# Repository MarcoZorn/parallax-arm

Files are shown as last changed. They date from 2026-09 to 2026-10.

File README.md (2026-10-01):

# Parallax Arm

Braccio robotico da scrivania a 4 assi, **solo servo SG90**, interamente stampabile in PLA, **zero saldature**.
Lo pilota un ESP32 e si controlla da una web app locale con digital twin 3D.

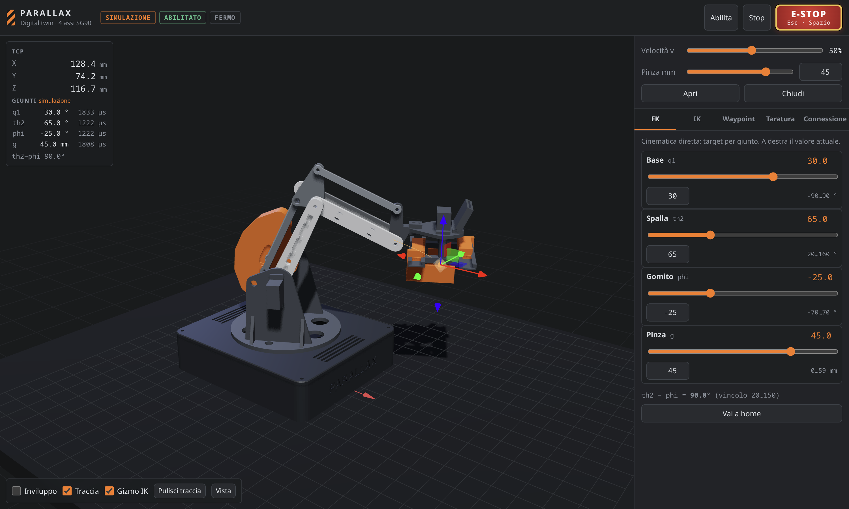
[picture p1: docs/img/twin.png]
Digital twin


| | |
|---|---|
| Assi | base, spalla, gomito + pinza parallela; pinza **sempre orizzontale** (doppio parallelogramma) |
| Sbraccio | 188 mm dall'asse spalla (th2 − phi ≥ 35°) |
| Payload | 50 g anche con la ESP32-CAM montata (SF ≥ 2 sulla coppia di stallo: `calc/` + simulazione MuJoCo in `sim/`) |
| Pinza | cremagliera simmetrica, corsa 0–59 mm |
| Motori | 4 × SG90 180°: spalla e gomito sulla torretta, contrappesi con piombi da pesca |
| Elettronica | ESP32 DevKit V1, PWM diretto dai GPIO, caricatore USB 5V 3A, morsetti WAGO |
| Software | firmware PlatformIO (WebSocket, planner sincronizzato), web app Vite + Three.js (FK, IK, waypoint, taratura, simulazione) |

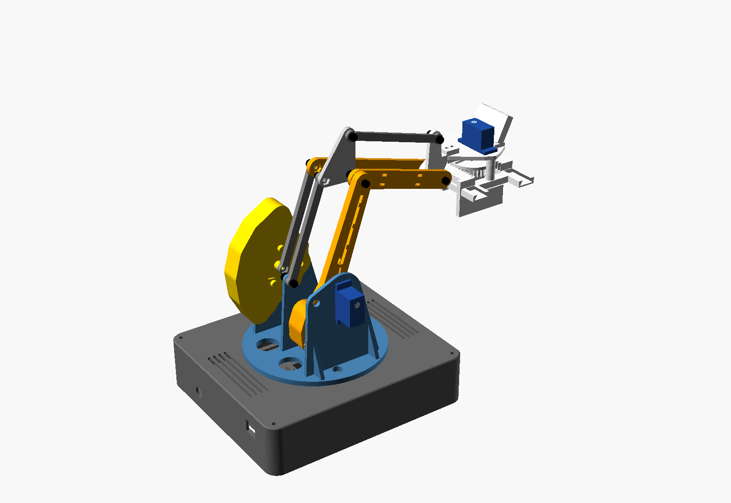
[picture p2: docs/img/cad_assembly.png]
Assieme CAD


## Come è fatto

Un SG90 da 1.6 kg·cm non regge un braccio seriale.

**Il servo del gomito è sulla torretta**, accanto a quello della spalla, e muove l'avambraccio con una manovella e una biella. Così nessun motore viaggia sul braccio.

Due parallelogrammi passivi tengono la pinza orizzontale, e i piombi da pesca sulle code di manovella e braccio compensano la gravità a qualsiasi angolo.

Ogni numero si può rilanciare:
- `python3 calc/torque.py` per le coppie, con le masse ricavate dagli STL;
- `cad/assembly.scad` per le collisioni tra tutte le parti, viti e dadi compresi, su una griglia di pose.

## Struttura

```
calc/torque.py        coppie statiche, contrappesi, pinza, corrente (con assert)
cad/params.scad       unica fonte delle quote e delle tolleranze
cad/*.scad            base, torretta, braccio, manovella, catena gomito, polso+pinza, provino tolleranze
cad/assembly.scad     assieme + verifica collisioni
cad/export.sh         rigenera STL di stampa, modelli del twin e rig.json
cad/stl/              STL pronti, già orientati sul piatto
firmware/             ESP32 (PlatformIO): LEDC, WiFi STA/AP, WebSocket, NVS, test nativi
web/                  digital twin e controllo (Vite + Three.js), build -> firmware/data
docs/                 analisi, cablaggio, protocollo, stampa e montaggio
```

## Avvio rapido

1. Stampa gli STL di `cad/stl/` (circa 230 g di PLA, niente supporti) e monta: [docs/04-stampa-e-montaggio.md](docs/04-stampa-e-montaggio.md).
2. Il provino di tolleranze è facoltativo: serve solo se qualcosa non calza.
3. Cablaggio: [docs/02-cablaggio.md](docs/02-cablaggio.md).
4. Carica firmware e web app:
   ```bash
   cd web && npm install && npm run build
   cd ../firmware && pio run -e esp32dev -t upload && pio run -e esp32dev -t uploadfs
   ```
   Poi apri `http://braccio.local`, oppure l'AP `BRACCIO` su `http://192.168.4.1`.

Senza hardware: `cd web && npm install && npm run dev`. La web app gira in simulazione con lo stesso profilo di moto del firmware.

## Test

```bash
python3 calc/torque.py                    # punti di progetto delle coppie
cd firmware && pio test -e native         # planner, limiti, mappatura µs
cd web && npm test                        # FK/IK andata e ritorno, profilo di moto
cad/check_grid.sh                         # collisioni su tutta la griglia di pose (lento)
sim/software/run_all.sh                   # firmware = twin, fuzz, protocollo end-to-end, UI
python3 sim/structural/run_all.py         # strutture, perni, ingranaggi, tolleranze (Monte Carlo)
python3 sim/electrical/run_all.py         # alimentazione nel tempo
sim/.venv/bin/python sim/dynamics/run_all.py   # dinamica MuJoCo (python3 -m venv sim/.venv && sim/.venv/bin/pip install mujoco numpy scipy matplotlib)
```

Esiti e limiti: [docs/05-verifiche.md](docs/05-verifiche.md).

## Documenti

- [01 — Analisi carichi e scelte di progetto](docs/01-analisi-e-piano.md)
- [02 — Cablaggio senza saldature](docs/02-cablaggio.md)
- [03 — Cinematica, taratura e protocollo](docs/03-protocollo.md)
- [04 — Stampa, ferramenta e montaggio](docs/04-stampa-e-montaggio.md)
- [05 — Verifiche e simulazioni](docs/05-verifiche.md): dinamica MuJoCo, strutture e tolleranze, alimentazione, software

## Licenza

MIT, vedi [LICENSE](LICENSE).

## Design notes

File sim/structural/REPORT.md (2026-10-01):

# BRACCIO — analisi strutturale e di tolleranze

Generato da `sim/structural/run_all.py` il 2026-10-01 sulle quote correnti di `cad/*.scad`
e sulle masse di `calc/torque.py`. PLA su Kobra S1: ugello 0.4, layer 0.2, 3 perimetri, gyroid 20%.
Materiale: E 3200 MPa nel piano / 2600 tra layer, rottura 50 / 27 MPa,
taglio interlaminare 15 MPa; sezioni con guscio pieno (perimetri 1.2, top/bottom 0.8) e nucleo gyroid al 12% di
rigidezza. Orientamenti di stampa: quelli di `cad/export.sh`. Carico di verifica: 50 g + ESP32-CAM, 2 piombi sulla manovella
e 4 sulla coda del braccio (punto di progetto di docs/01).

## Esiti

| verifica | ESITO | in breve |
|---|---|---|
| 1. Link e bielle: tensioni e freccia al TCP | **KO** | tensioni OK nei link (SF din min 1.9), dito ganascia SF 2.7 allo stallo; freccia TCP statica 5.5 mm in home, 26 mm a sbraccio |
| 2. Perni M3, fori e alberi dei servo | **KO** | perno E: p bordo din 47.9 MPa, vite 724 MPa; momento albero spalla 708 N·mm statico |
| 3. Pignone e cremagliere m1 + controlli STL | **OK** | denti OK (σ pignone 2.4 MPa allo stallo); ricoprimento 1.53 col gioco; ganasce: ok |
| 4. Code di rondine: attrito e impuntamento | **riserva** | presa 1.9 N/dito con μ 0.35 (rendimento 0.40), richiesti 1.6 N; impuntamento solo con μ > 1.08 |
| 5. Incastri a scatto (culla ESP32) | **OK** | ε 0.20% (ok), P(scheda non trattenuta) 0% |
| 6. Autofilettanti e dadi incassati | **riserva** | estrazione OK; sedi dadi: ok, parete minima 0.55 mm |
| 7. Scorrimento viscoso e temperatura | **KO** | servo gomito in home 50 g: +59 K; freccia TCP x1.4 dopo 100 h a 23 °C |
| 8. Monte Carlo delle tolleranze | **KO** | home: accuratezza p95 16.2 mm, RP p95 14.9 mm (scenario B); squadretta non entra 0%, SG90 nelle guance 10% |

Il quadro in una riga: **i pezzi non si rompono, il braccio è cedevole**. Le tensioni sono basse quasi ovunque (eccezioni: il
dito della ganascia, il perno E e gli alberi dei servo). La rigidezza invece è dominata dall'eccentricità di ~33 mm tra il piano
del braccio e quello della biella motrice: la forza della biella flette fuori piano braccio, guancia e albero del servo spalla, e il
parallelogramma trasforma quelle piccole rotazioni in rotazioni dell'avambraccio, amplificate da 1/sin(e) vicino a e = 20°.
Ci sono poi tre difetti CAD che vanno corretti comunque (ganasce, dadi della staffa, dado di U corto).

## 1. Link e bielle: tensioni e freccia al TCP — KO

Carichi: 50 g + ESP32-CAM, 2 piombi manovella + 4 braccio. Statico = posa peggiore sulla griglia
(th2 20…160, phi −70…70, vincolo e = th2 − phi in 20…150, passo 5°). Dinamico = statico x 2.
Stallo = servo gomito a 2 kg·cm contro un ostacolo con e = 20° (biella 28.7 N).
Ammissibili: 50 MPa nel piano dei layer, 27 MPa tra layer, 15 MPa taglio interlaminare.
ESITO sul dinamico: OK se SF ≥ 2, riserva se 1.2–2, KO sotto.

| membro | posa peggiore th2/phi | σ stat MPa | σ din MPa | σ stallo MPa | amm. MPa | SF din | ESITO | nota |
|---|---|---|---|---|---|---|---|---|
| braccio (in piano) | 20/0 | 2.97 | 5.95 | 6.69 | 50 | 8.4 | OK | flessione nel piano + fuori piano + torsione, sezione al foro cavo x=20 |
| avambraccio piastra R (di fianco) | 60/0 | 0.90 | 1.80 | 2.02 | 50 | 27.8 | OK | momento della leva B al perno E |
| avambraccio taglio tra layer | 20/0 | 0.34 | 0.68 | 0.77 | 15 | 22.0 | OK | taglio all'asse neutro = piano dei layer |
| biella motrice (assiale) | 20/0 | 1.18 | 2.36 | 2.65 | 50 | 21.2 | OK | sezione netta all'occhio |
| biella livell. 1 (assiale) | 20/-20 | 0.56 | 1.13 | 1.27 | 50 | 44.4 | OK | sezione netta all'occhio |
| biella livell. 2 (assiale) | 20/-70 | 0.50 | 1.00 | 0.39 | 50 | 50.0 | OK | sezione netta all'occhio |
| triangolo (leve P1/U) | 20/-20 | 1.89 | 3.78 | 4.26 | 50 | 13.2 | OK |  |
| manovella | 20/0 | 4.53 | 9.06 | 10.20 | 50 | 5.5 | OK | piastra 4 mm, sezione 12 x 4 al mozzo |
| montante G (in piedi) | 20/-20 | 3.60 | 7.20 | 8.11 | 27 | 3.7 | OK | lastra 16 x 3 alla base, tensione verticale tra layer |
| guancia spalla (in piedi) | 55/35 | 5.33 | 10.65 | 7.20 | 27 | 2.5 | OK | flessione fuori piano sopra i fazzoletti |
| guancia spalla torsione | 20/0 | 3.88 | 7.76 | 8.74 | 15 | 1.9 | riserva | torsione attorno a Z |
| staffa polso (leva V) | 20/-70 | 0.49 | 0.99 | 1.11 | 50 | 50.5 | OK |  |
| dito ganascia: torsione gambo | presa | 4.45 | - | 5.56 | 15 | 2.7 (stallo) | OK | gambo 6 x 5, leva 30 mm, taglio sui piani dei layer |

Dito ganascia: freccia sotto la presa di stallo 0.82 mm. Con gambo 6 mm e dito spesso 5 mm il taglio
scende da 5.6 a 5.6 MPa (SF 2.7).

**Tensioni basse ovunque, tranne il dito.** I link reggono con margini ampi: il problema è la **rigidezza**.

#### Freccia elastica al TCP (statica, mm; colonne x,z nel piano, y laterale)

La catena è sommata risolvendo i due parallelogrammi con le cedevolezze di ogni elemento (`chain.py`).
Il meccanismo che domina: il braccio (y -22.4) e la biella motrice (y 11.0) stanno su piani distanti
33 mm. La forza della biella arriva al braccio tramite la vite E a sbalzo e lo flette **fuori piano**;
la stessa eccentricità torce/flette la guancia del servo spalla e l'albero dell'SG90. Ogni rotazione fuori piano θ sposta il piano
della biella di θ·Δy lungo il braccio, e il parallelogramma lo trasforma in una rotazione dell'avambraccio di θ·Δy/(20·sin e).

| posa | dx | dz | dy | |δ| statico | |δ| x2 | A: nervature braccio 6 mm + fazzoletti 50 mm |δ| | B: A + mozzo E 14 mm e perno d4 |δ| |
|---|---|---|---|---|---|---|---|
| home (90/0, e=90) | -0.68 | -5.44 | +0.59 | 5.51 | 11.02 | 5.84 | 4.39 |
| sbraccio (20/0, e=20) | -7.25 | -25.18 | +3.77 | 26.47 | 52.94 | 26.70 | 20.00 |
| basso (35/-60, e=95) | -3.14 | -2.86 | +0.23 | 4.25 | 8.50 | 4.34 | 3.25 |
| alto (130/50, e=80) | +1.59 | -3.44 | +0.72 | 3.85 | 7.70 | 4.02 | 3.01 |
| ripiegato (150/0, e=150) | -2.76 | -18.15 | -0.81 | 18.37 | 36.75 | 18.80 | 12.93 |

Contributi (modulo del solo contributo, mm):

| posa | braccio | perno E | guancia/albero spalla | manovella/guancia gomito | giunti A/B | bielle | giunti livellamento | montante G |
|---|---|---|---|---|---|---|---|---|
| home | 0.96 | 1.75 | 2.17 | 0.31 | 0.26 | 0.03 | 0.06 | 0.00 |
| sbraccio | 6.48 | 10.99 | 8.45 | 1.87 | 2.15 | 0.22 | 0.37 | 1.44 |
| basso | 0.79 | 1.33 | 1.32 | 0.13 | 0.13 | 0.04 | 0.18 | 0.41 |
| alto | 0.76 | 1.26 | 1.41 | 0.18 | 0.17 | 0.02 | 0.10 | 0.14 |
| ripiegato | 3.27 | 5.88 | 4.81 | 0.97 | 1.06 | 0.10 | 0.18 | 0.61 |

Effetto di e minimo (sbraccio con avambraccio orizzontale):

| lim e min ° | sbraccio mm | |δ| attuale | |δ| variante B | biella motrice N |
|---|---|---|---|---|
| 20 | 197 | 26.5 | 20.0 | 12.7 |
| 30 | 191 | 15.6 | 11.7 | 8.7 |
| 35 | 188 | 12.7 | 9.6 | 7.6 |
| 45 | 179 | 9.3 | 7.1 | 6.2 |

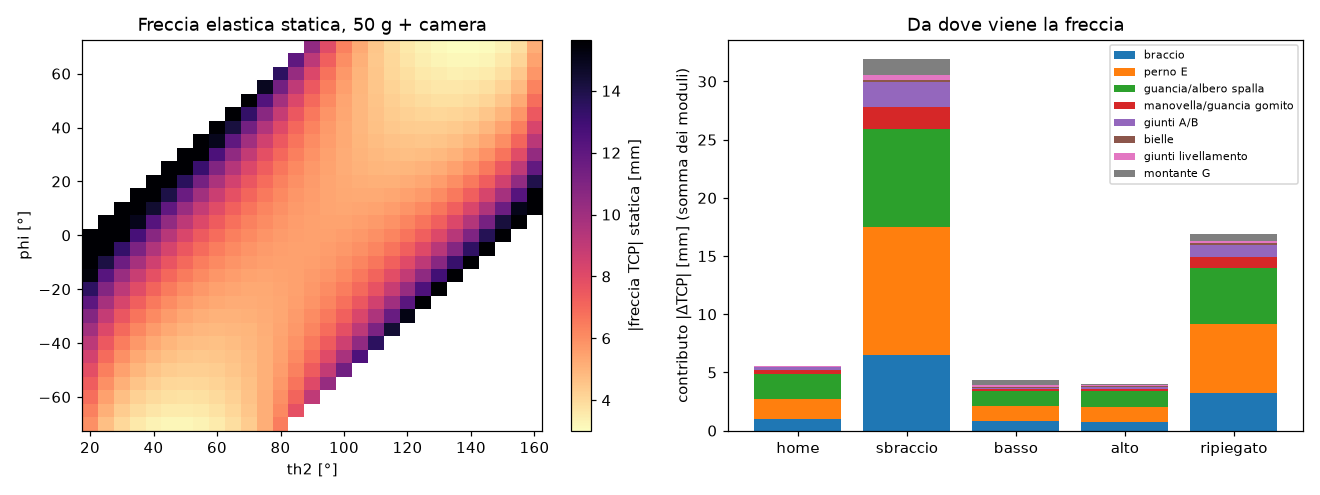
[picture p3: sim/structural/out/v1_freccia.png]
freccia


Ipotesi del modello (da tarare con una prova): rigidezza di bordo dei fori 1600 N/mm per mm, albero SG90
6e+04 N·mm/rad, guance come lastre 3 mm (fazzoletti rigidi a torsione), vite E con nocciolo d 2.39.
Prova consigliata: in `home` con 50 g in pinza misura l'abbassamento del TCP con un calibro a corsoio sul tavolo:
il modello prevede 5.5 mm, di cui la parte da braccio+guancia+albero sparisce se premi a mano il gomito verso il servo.

## 2. Perni M3, fori e alberi dei servo — KO

Pressione di contatto p = F/(d·t) nei fori (con il momento della vite dove il perno è a sbalzo:
p = F/(d·L) + 6·F·a/(d·L²)). Ammissibile breve 35 MPa, sostenuta per ore 10 MPa
(oltre, il foro si ovalizza per scorrimento viscoso). Flessione della vite sul nocciolo d 2.39 (vite tutta filettata
dei kit), confrontata con inox A2-70 (450 MPa); una 8.8 arriva a 640.

| giunto | posa peggiore | F stat N | p stat MPa | dove | p din MPa | SF p din | p in home MPa | M vite N·mm | σ vite din MPa | SF vite | ESITO |
|---|---|---|---|---|---|---|---|---|---|---|---|
| E (M3x40) | 20/0 | 19.2 | 24.0 | foro nel braccio (bordo, con il momento) | 47.9 | 0.7 | 9.0 | 485 | 724 | 0.6 | KO |
| W (M3x35) | 90/70 | 5.0 | 0.3 | piastra R | 0.5 | 64.1 | 0.1 | 26 | 39 | 11.5 | OK |
| A (M3x14) | 20/0 | 12.7 | 15.5 | foro nella manovella (bordo) | 31.1 | 1.1 | 5.3 | 116 | 173 | 2.6 | KO |
| B (M3x8) | 20/0 | 12.7 | 7.9 | piastra R (foro + dado, bordo) | 15.7 | 2.2 | 2.7 | 57 | 86 | 5.3 | OK |
| G (M3x12) | 20/-20 | 6.1 | 6.1 | montante (bordo) | 12.2 | 2.9 | 2.1 | 24 | 36 | 12.4 | OK |
| P1 (M3x8) | 20/-20 | 6.1 | 0.5 | biella 1 | 1.0 | 34.6 | 0.2 | 26 | 39 | 11.7 | OK |
| U (M3x6) | 20/-70 | 4.1 | 0.5 | biella 2 | 0.9 | 38.9 | 0.2 | 15 | 23 | 19.8 | OK |
| V (M3x12) | 20/-70 | 4.1 | 0.5 | biella 2 | 0.9 | 38.9 | 0.2 | 15 | 23 | 19.8 | OK |

Osservazioni:
- **E** è l'unico perno serio: è una mensola di 26 mm dal braccio, e la biella motrice
  carica la piastra R all'estremità libera. Il momento genera nel foro del braccio (lungo solo 6.5 mm)
  una pressione di bordo alta, che in poche ore di posa ovalizza il foro: il gioco del gomito cresce col tempo.
  Con mozzo d12 x 8 mm (foro lungo 14) la pressione di bordo scende di circa (6.5/14)² = 0.22 volte.
- **A** è il secondo: vite a sbalzo di 9.1 mm dalla piastra della manovella da 4 mm.
- I perni ruotano sul filetto (viti dei kit tutte filettate): il filetto lima il foro. Dove ruota qualcosa (E, W, G, V, A, B, P1, U)
  conviene una vite a gambo parziale (ISO 4762 M3x40: filetto 18 mm, il gambo liscio copre braccio, piastra L e triangolo)
  oppure un tubetto di ottone 4/3 mm incollato nel foro come boccola.
- **A, B, P1, U ruotano con un dado normale nella sede**: la vite gira insieme alla parte che ruota e si avvita o svita da sola
  a ogni ciclo. Serve frenafiletti medio (o dadi autobloccanti sottili, sedi da 3.0 mm invece di 2.6).

Impegno del filetto nel dado incassato, lunghezze di docs/04 (dado da 2.4 mm a filo della faccia):

| giunto | vite | impegno mm | filetti | esito |
|---|---|---|---|---|
| A | M3x14 | 2.4 | 4.8 | OK |
| B | M3x8 | 1.9 | 3.8 | corto |
| P1 | M3x8 | 2.4 | 4.8 | OK |
| U | M3x6 | 1.4 | 2.8 | corto |

Nota: l'intestazione di `cad/linkage.scad` indica A M3x20, B/P1/U M3x10, V M3x10, mentre docs/04 dice A M3x14, B/P1 M3x8,
U M3x6, V M3x12. Le lunghezze di docs/04 sono quelle giuste per A (con M3x20 la punta urta il montante G), per U no.

Alberi dei servo (SG90: boccole in plastica, nessun cuscinetto). Il momento flettente è preso rispetto alla boccola
(~3.5 mm dentro la guancia) e confrontato, come regola pratica, con la coppia nominale (157 N·mm):

| albero | posa peggiore | F radiale N | M stat N·mm | M din N·mm | rif. N·mm | SF | ESITO |
|---|---|---|---|---|---|---|---|
| albero spalla | 20/0 | 19.6 | 708 | 1417 | 157 | 0.11 | KO |
| albero gomito | 20/0 | 12.5 | 255 | 509 | 157 | 0.31 | KO |

La biella motrice chiude il suo anello di forze attraverso **entrambi** gli alberi (braccio → albero spalla → torretta →
albero gomito → manovella): la forza radiale non è "< 1.5 N" come in docs/01, ma 4–13 N statici, con braccio di leva fino
a 38 mm.

## 3. Pignone e cremagliere m1 + controlli STL — OK

Pignone m1 z32 (r 16.0), due cremagliere: F tangenziale = T/(2r) per dente. Fascia utile 5.7 mm
(sovrapposizione pignone/cremagliera). Lewis: Y pignone 0.365, cremagliera 0.485.
Hertz al primitivo con E* = E/2(1−ν²).

| caso | F per dente N | σ Lewis pignone MPa | σ Lewis cremagliera MPa | τ piede cremagliera MPa | p Hertz MPa |
|---|---|---|---|---|---|
| stallo dichiarato 1.6 kg·cm | 4.9 | 2.4 | 1.8 | 0.52 | 9.6 |
| x2 dinamico | 9.8 | 4.7 | 3.5 | 1.04 | 13.5 |
| stallo reale 2.0 kg·cm | 6.1 | 2.9 | 2.2 | 0.65 | 10.7 |

Ammissibile a fatica per denti in PLA ~18 MPa (35% della rottura): SF sul dinamico 3.7.
I denti non sono il limite: il limite di forza della pinza è l'attrito delle guide (§4) e il dito (§1).

**Salto dei denti.** La spinta radiale F·tan20° = 1.78 N allontana la cremagliera finché
il gioco della coda di rondine lo permette: 0.30 mm (clr_slide 0.3).
Ricoprimento 1.82 a gioco nullo, 1.53 con la cremagliera tutta indietro; si salta sotto 1.0, cioè oltre
0.83 mm di allontanamento. Gioco sul dente 0.37 mm → ±0.18 mm per dito.

**Orientamento.** Il pignone è stampato in piano: profilo nel piano XY, preciso. Le ganasce sono stampate di fianco
(Y della cremagliera in verticale): i fianchi dei denti diventano superfici a 20° dall'orizzontale, uno dei due è uno
**sbalzo a 70°** e il gradino dei layer da 0.16 vale 0.15 mm sul fianco, quanto tutto il gioco di progetto (0.15).
Le tensioni di piede restano nel piano dei layer (σ lungo X), il taglio al piede va sui piani dei layer ma è < 1 MPa.

Controllo degli STL generati con gli stessi `part` di `cad/export.sh` (orientati come si stampano): gusci connessi,
area a sbalzo oltre 45° e 60° dalla verticale e soffitti orizzontali (mm², piano del piatto escluso).

| parte | gusci | sbalzo >45° mm² | >60° mm² | soffitti mm² |  |
|---|---|---|---|---|---|
| 00_tolerance_coupon | 27 | 0 | 0 | 710 |  |
| 01_base_tray | 1 | 21 | 14 | 92 |  |
| 03_turret | 1 | 37 | 21 | 860 |  |
| 02_base_lid | 2 | 0 | 0 | 473 | labbro appoggiato sul piano (a contatto: in stampa si fonde) |
| 04_upper_arm | 1 | 0 | 0 | 489 |  |
| 05_upper_arm_lid | 1 | 0 | 0 | 0 |  |
| 06_crank | 1 | 0 | 0 | 1685 |  |
| 07_crank_lid | 1 | 0 | 0 | 0 |  |
| 08_crank_spacer | 1 | 0 | 0 | 0 |  |
| 09_drive_rod | 1 | 0 | 0 | 22 |  |
| 10_lev_rod | 1 | 0 | 0 | 0 |  |
| 11_lev_rod2 | 1 | 0 | 0 | 0 |  |
| 12_lev_link | 1 | 0 | 0 | 22 |  |
| 13_forearm | 1 | 110 | 61 | 73 |  |
| 14_elbow_wrist_spacers | 3 | 0 | 0 | 0 |  |
| 15_wrist_bracket | 1 | 20 | 13 | 0 |  |
| 16_gripper_housing | 1 | 0 | 0 | 2 |  |
| 17_gripper_base_plate | 1 | 0 | 0 | 40 |  |
| 18_gripper_pinion | 1 | 0 | 0 | 144 |  |
| 19_gripper_jaw_x2 | 1 | 187 | 187 | 0 |  |
| 20_esp32cam_cradle | 1 | 90 | 90 | 16 |  |

## 4. Code di rondine: attrito e impuntamento — riserva

Leve (frame cremagliera): la presa avviene sull'asse del pignone, 16.0 mm in X e 18.4 mm in Z
dalla linea dei denti. La coppia F·(dx, dz) ruota la cremagliera nella guida (lunga 40 mm, sempre tutta impegnata):
due reazioni alle estremità, amplificate dal cuneo della coda di rondine a 60° (1.73 per le forze laterali,
2 verso l'alto). In più la spinta radiale del dente (tan 20°).

| μ | rendimento presa | forza per dito N | rispetto al richiesto | rendimento con guida 50 mm |
|---|---|---|---|---|
| 0.15 | 0.64 | 3.14 | 1.92 | 0.68 |
| 0.25 | 0.50 | 2.44 | 1.49 | 0.54 |
| 0.35 | 0.40 | 1.94 | 1.19 | 0.44 |
| 0.5 | 0.29 | 1.41 | 0.86 | 0.33 |

Forza al dente 4.9 N per cremagliera (1.6 kg·cm); torque.py assume 4.9 N per dito e ne chiede 1.6.
Con μ 0.35 si perde il 60% nelle guide: la presa reale è 1.9 N per dito
(margine 1.19 sul richiesto, che già contiene SF 2).

**Effetto cassetto.** In corsa libera la spinta al dente è sfalsata dal centro guida di 6.2 mm (X) e
5.1 mm (Z): si impunta solo con μ > 1.08. Rapporto lunghezza guida / leva della presa
1.64 (regola pratica ≥ 1.5): ok, ma con poco margine.

**Gioco.** Con clr_slide 0.3 la cremagliera ruota liberamente di 0.99° (imbardata) e 0.86° (beccheggio)
prima di toccare: il centro del dito si sposta di ±0.28 mm. I fianchi a 60° della gola, stampata in piano, hanno il
gradino dei layer da 0.2 mm (creste da 0.10 mm): i primi movimenti le spianano.

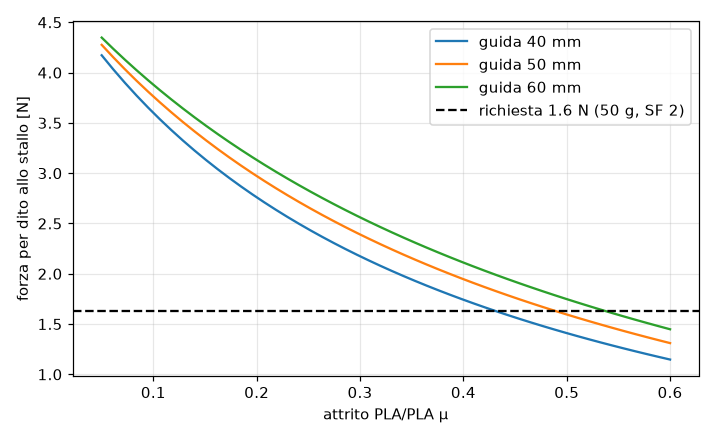
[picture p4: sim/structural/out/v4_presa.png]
presa


## 5. Incastri a scatto (culla ESP32) — OK

Lamella 2 x 5 mm alta 32.2 mm (dente a 29.7 mm dal fondo), stampata in piedi:
la tensione di flessione al piede è verticale, cioè **tra i layer** (E 2600 MPa, allungamento a rottura ~1%,
non il 2% del PLA nel piano). La lamella sta a clr_pocket 0.2 dal bordo del PCB, quindi il dente sovrappone
snap_hook − clr_pocket al PCB nominale (28.3 mm). Forze per **due** ganci.

| snap_hook mm | sovrapposizione mm | ε al piede % | forza laterale N | inserimento N (2 ganci) | sfilamento N (2 ganci) | P(non trattiene) % | P(ε > 1%) % |
|---|---|---|---|---|---|---|---|
| 0.8 | 0.60 | 0.20 | 0.60 | 0.90 | 18.6 | 0.0 | 0.00 |
| 0.6 | 0.40 | 0.14 | 0.40 | 0.51 | 13.4 | 1.7 | 0.00 |
| 0.8 | 0.60 | 0.20 | 0.60 | 0.90 | 18.6 | 0.0 | 0.00 |

Monte Carlo (20000): PCB dei cloni 28.0–28.6 mm, dente stampato più basso di 0.1 ± 0.05 (è largo quanto una linea),
posizione della lamella ±0.05. "Non trattiene" = sovrapposizione < 0.05 mm su almeno un lato.

La lamella è lunghissima rispetto al dente: la deformazione è un decimo del limite, ma il gancio tiene poco e il dente
da 0.4 mm è al limite di ciò che un ugello da 0.4 riproduce. Il rischio non è rompere, è che la scheda non resti in sede
(i Dupont tirano la scheda verso il basso: lì la spingono contro gli appoggi, quindi il gancio lavora poco in esercizio).

## 6. Autofilettanti e dadi incassati — riserva

Estrazione: taglio su un cilindro di diametro medio tra vite e preforo, sui piani dei layer
(τ 15 MPa), filetto formato proporzionale a (d − preforo). Il carico è x2. Viti delle linguette:
oltre alla coppia, riprendono il momento flettente sull'albero spalla di §2 (708 N·mm) come coppia di forze a passo
27.8 mm.

| dove | vite | preforo | impegno mm | F estrazione N | carico N | SF | ESITO | nota |
|---|---|---|---|---|---|---|---|---|
| coperchio base (4) | M3 | 2.5 | 5.6 | 538 | 1.0 | 269 | OK | colonnine d9 verticali |
| piastra pinza (2) | M3 | 2.5 | 9.3 | 893 | 6.0 | 74 | OK | colonnine d7, regge cremagliere e payload |
| culla camera (2) | M3 | 2.5 | 3.0 | 288 | 1.0 | 144 | OK | solo lo spessore del piano (3 mm) |
| linguette SG90 guance (2/servo) | M2 | 1.6 | 3.0 | 204 | 31.1 | 3 | OK | fori orizzontali, M2 del servo |

Preforo 2.5 per M3 autofilettante: corretto per PLA (2.4–2.6). I fori stampati escono ~0.1 più stretti: la vite entra dura,
le colonnine d7/d9 hanno parete ≥ 2.25 mm (≥ 0.75·d), non si spaccano. Il rischio vero è stringere troppo: nel PLA una M3 in
6 mm spana a ~0.4 N·m, a mano con un cacciavite piccolo ci si arriva facilmente. I fori pilota delle linguette (1.6 per la M2
del servo) stanno in guance da 3 mm stampate in piedi, con asse orizzontale: lì la vite apre i layer, avvitare piano.

Dadi incassati (chiave 5.5 + 2·clr_pocket = 5.9, vertici a
6.81): parete minima tra la sede e qualunque altro
contorno, misurata sulla sezione del CAD a metà sede. 2 linee da 0.4 = 0.8 mm è il minimo che il slicer stampa pieno;
sotto resta una linea sola (o il riempimento dei vuoti) e sono proprio i vertici del dado a spingerla quando si stringe.
ESITO: OK ≥ 1.2 mm (3 perimetri), riserva sotto, KO se le sedi si toccano.

| sede | centro (x, y) | parete min mm | linee da 0.4 |  | ESITO |
|---|---|---|---|---|---|
| biella motrice (A) | (0.0, 0.0) | 0.59 | 1.5 |  | riserva |
| triangolo (P1, U) | (-20.0, 0.0) | 1.59 | 4.0 |  | OK |
| triangolo (P1, U) | (0.0, -30.0) | 1.59 | 4.0 |  | OK |
| avambraccio piastra R (B) | (-20.0, 0.0) | 3.59 | 9.0 |  | OK |
| coda braccio (coperchio) | (-45.9, -8.1) | 1.55 | 3.9 |  | OK |
| coda braccio (coperchio) | (-45.9, 8.1) | 1.55 | 3.9 |  | OK |
| manovella (coperchio) | (22.0, -13.9) | 1.59 | 4.0 |  | OK |
| manovella (coperchio) | (22.0, 13.9) | 1.59 | 4.0 |  | OK |
| piano pinza (staffa) | (15.5, -1.5) | 0.55 | 1.4 |  | riserva |
| piano pinza (staffa) | (23.0, -1.5) | 1.05 | 2.6 |  | riserva |

## 7. Scorrimento viscoso e temperatura — KO

Modello: cedevolezza J(t,T) = [1 + a·(t·a_T)^0.25]/E(T), a tarato perché a 23 °C dopo 1000 h il modulo apparente sia
E/1.8; spostamento tempo-temperatura di Arrhenius (Ea 200 kJ/mol); E(T) cala del 10% a 40 °C e del 30% a 50 °C
(Tg del PLA ~58 °C). Valori tipici di letteratura per PLA stampato: ordine di grandezza, non dati del filamento.

Fattore di aumento della freccia (rispetto all'elastica a 23 °C):

| T | 1 h | 8 h | 100 h | 1000 h |
|---|---|---|---|---|
| 23 °C | 1.14 | 1.24 | 1.45 | 1.80 |
| 35 °C | 1.38 | 1.61 | 2.10 | 2.91 |
| 40 °C | 1.59 | 1.91 | 2.62 | 3.79 |
| 45 °C | 1.93 | 2.41 | 3.45 | 5.19 |
| 50 °C | 2.54 | 3.29 | 4.93 | 7.66 |

**Temperatura dei servo.** Il driver analogico dell'SG90 manda impulsi a piena tensione con duty ~ coppia/stallo, quindi
tenere una coppia costa P ≈ duty·5 V·0.75 A. Con R_th 35 K/W tra cassa e aria (assunzione):

| posa tenuta | spalla: duty / P / ΔT cassa | gomito: duty / P / ΔT cassa |
|---|---|---|
| home, pinza vuota | 0.00 / 0.00 W / +0 K | 0.13 / 0.50 W / +18 K |
| home, 50 g + camera | 0.00 / 0.00 W / +0 K | 0.45 / 1.69 W / +59 K |
| sbraccio, 50 g + camera | 0.47 / 1.76 W / +62 K | 0.45 / 1.69 W / +59 K |

Il gomito con 2 piombi resta sempre caricato (scelta voluta, per non flottare nel gioco): in home con 50 g + camera la cassa
arriva a ~82 °C a regime (costante di tempo di qualche minuto). È sopra la Tg del PLA (~58 °C): il bordo della
finestra nella guancia e le viti delle linguette perdono presa. Già a 45 °C il PLA scorre 1.9
volte più che a 23 °C. Lo stesso vale per la spalla tenuta a sbraccio. È anche un limite del servo, non solo del PLA.

Freccia del TCP sotto carico costante (mm; la parte dell'albero del servo non scorre):

| posa | elastica | 23 °C 8 h | 23 °C 100 h | 40 °C 8 h | 40 °C 100 h | 50 °C 8 h | 50 °C 100 h |
|---|---|---|---|---|---|---|---|
| home, 50 g + camera | 5.5 | 6.5 | 7.4 | 9.4 | 12.3 | 15.2 | 22.2 |
| sbraccio, 50 g + camera | 26.5 | 31.4 | 35.7 | 45.1 | 59.6 | 73.5 | 107.1 |

Tensioni sostenute in `home` contro il limite a lungo termine (30% della rottura, ridotto con E(T); fori: 10 MPa):

| dove | valore MPa | T locale °C | limite MPa | ESITO |
|---|---|---|---|---|
| braccio (fuori piano), home | 1.0 | 23 | 15.0 | OK |
| foro E nel braccio, bordo | 9.0 | 23 | 10.0 | riserva |
| foro A nella manovella, bordo | 5.3 | 23 | 10.0 | OK |
| guancia spalla attorno al servo | 3.2 | 23 | 8.1 | OK |
| guancia gomito attorno al servo | 1.0 | 82 | 0.0 | KO |
| dito che stringe a stallo per ore | 4.4 | 23 | 4.5 | riserva |

I piombi non sono un problema di scorrimento: 20 g ciascuno, tensioni nelle sedi < 0.1 MPa. Lo sono indirettamente: tengono
il braccio bilanciato, quindi la spalla in home lavora a coppia quasi nulla e resta fredda.

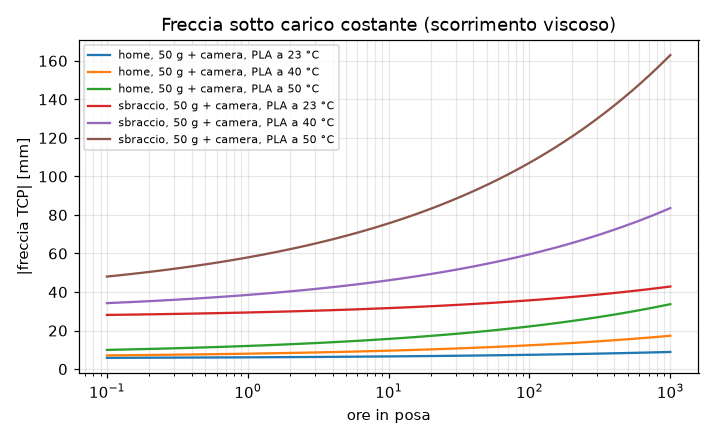
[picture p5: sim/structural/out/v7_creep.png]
creep


## 8. Monte Carlo delle tolleranze — KO

2000 robot virtuali x 10 arrivi per posa (20000 campioni), payload 30 g senza camera,
taratura in home a pinza vuota (si legge l'angolo vero di braccio, avambraccio e base; errore di lettura ±0.3°, scala ±0.3°/90°).
Accuratezza = distanza del baricentro degli arrivi dal punto comandato; ripetibilità = RP ISO 9283 (media + 3σ delle distanze
dal baricentro). Errore 3D: piano XZ dal solutore esatto dei parallelogrammi, laterale da imbardata della base e flessione.

Fonti e distribuzioni:
- fori stampati -0.08 ± 0.06 mm sul diametro, viti M3 2.88–2.98; giochi radiali = metà della somma dei due fori;
  un perno con forza > 0.3 N sta appoggiato dal lato del carico (offset ripetibile), sotto è in un punto a caso del gioco;
- interasse dei fori ±0.07 mm, ritiro del PLA 0–0.4% uguale per tutto il robot;
- asse del servo gomito rispetto a quello della spalla ±0.15 mm (finestre + linguette);
- SG90: banda morta 5–10 µs (0.45–0.9°), cedimento sotto carico fino a 2–6° alla coppia di stallo (anello proporzionale),
  gioco ingranaggi 1–2° (solo scenario B), scanalato 0.2–0.6°, squadretta nella tasca dove non è avvitata (torretta, manovella);
  sotto 5 N·mm di coppia il giunto non è appoggiato a un lato e si ferma in un punto a caso;
- base: attrito della corona (44 N·mm) ferma la torretta prima del bersaglio, dal lato da cui arriva;
- viti E e A inclinate nel foro se il loro momento supera il precarico (0–40 N sulla testa);
- cedevolezza strutturale di §1 con incertezza ±30%.

Scenario A: l'anello del servo compensa il gioco degli ingranaggi (il potenziometro è sull'uscita). Scenario B: no.

| scenario | posa | accuratezza mediana mm | accuratezza p95 mm | RP mediana mm | RP p95 mm |
|---|---|---|---|---|---|
| anello chiuso | home | 10.5 | 15.3 | 7.5 | 11.5 |
| anello chiuso | sbraccio | 40.4 | 47.2 | 12.2 | 18.6 |
| anello chiuso | basso | 11.5 | 15.8 | 9.0 | 14.0 |
| anello chiuso | alto | 11.3 | 14.1 | 2.6 | 4.0 |
| gioco SG90 non compensato | home | 11.5 | 16.2 | 10.3 | 14.9 |
| gioco SG90 non compensato | sbraccio | 42.6 | 49.2 | 16.3 | 24.1 |
| gioco SG90 non compensato | basso | 13.1 | 17.5 | 12.3 | 17.9 |
| gioco SG90 non compensato | alto | 12.3 | 15.3 | 3.5 | 5.2 |

Sensibilità (scenario B, una fonte alla volta + taratura; p95 in mm):

| fonte | home accuratezza | home RP | sbraccio accuratezza | sbraccio RP |
|---|---|---|---|---|
| banda morta | 1.95 | 1.72 | 3.14 | 2.86 |
| cedimento servo | 4.77 | 6.37 | 7.81 | 10.23 |
| gioco ingranaggi SG90 | 3.25 | 3.88 | 5.35 | 6.35 |
| squadrette | 3.49 | 4.80 | 5.68 | 7.66 |
| giochi perni | 4.29 | 0.00 | 12.20 | 0.00 |
| viti E/A inclinate | 7.46 | 0.00 | 19.44 | 0.00 |
| lunghezze stampate | 1.71 | 0.00 | 4.27 | 0.00 |
| assi dei servo | 1.43 | 0.00 | 3.61 | 0.00 |
| cedevolezza struttura | 3.27 | 0.00 | 22.60 | 0.00 |
| taratura | 1.38 | 0.00 | 2.01 | 0.00 |

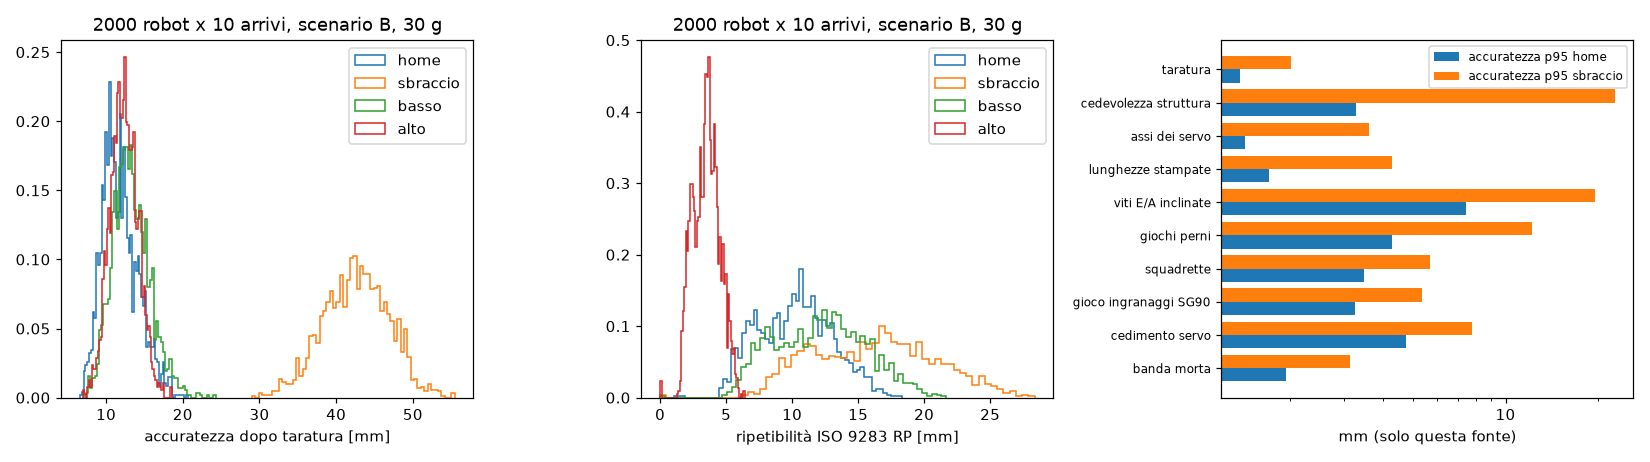
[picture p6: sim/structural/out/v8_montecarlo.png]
mc


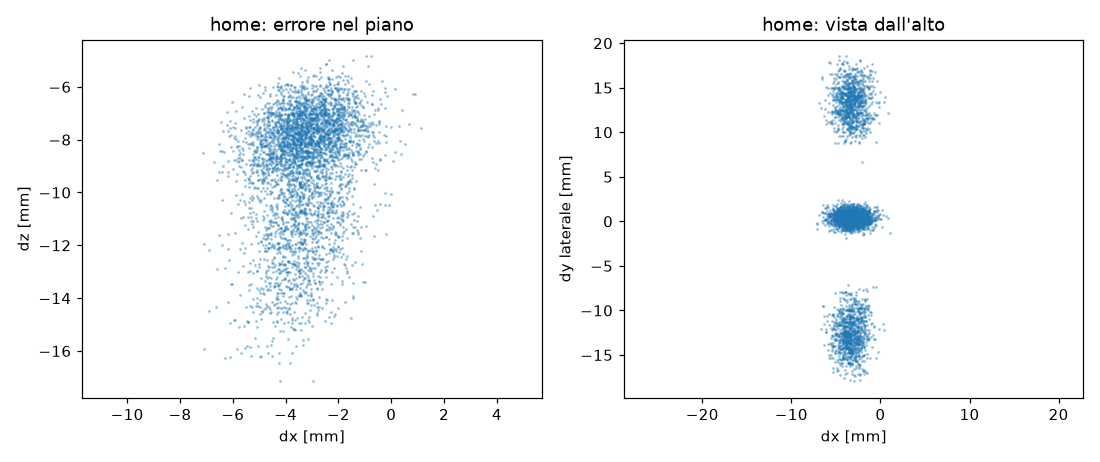
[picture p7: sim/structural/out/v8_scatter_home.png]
scatter


#### Accoppiamenti (100000 campioni)

Componenti reali: SG90 cloni 22.5–23.2 x 12.0–12.6, squadrette 31–33.5 mm (punte 3.8–4.2, mozzo 6.9–7.3), dadi M3
chiave 5.32–5.50, piombi 22.18 x 13.7 (±0.15 / ±0.10 nel lotto). Fori/tasche stampati -0.08 ± 0.06,
lunghezze delle tasche −0.10 ± 0.07, ponti delle finestre verticali che calano 0.05–0.3, piede d'elefante 0–0.2 sulle aperture
appoggiate al piatto, creste dei layer 0–0.1 sui fianchi della gola a coda di rondine.

| accoppiamento | P(non entra senza limare) % | P(gioco eccessivo) % | nota |
|---|---|---|---|
| SG90 nelle finestre delle guance (ponte in alto) | 10.4 | 9.4 | finestra verticale: il lato alto è un ponte che cala |
| SG90 nel piano pinza (stampato capovolto) | 3.5 | – | foro sul piatto: piede d'elefante 0–0.2 |
| SG90 nella torre della base | 0.1 | – |  |
| squadretta nella tasca (horn_len 33.5) | 0.1 | 65.6 | gioco angolare mediano 1.2° dove non è avvitata |
| dado M3 nella sede esagonale | 0.0 | 1.7 | gioco eccessivo = il dado gira nella sede |
| piombo nella sede del braccio | 0.4 | 0.1 | gioco eccessivo = sporge oltre la sede, il coperchio non chiude |
| piombo nella sede della manovella (aperta sul piatto) | 5.5 | 0.1 | piede d'elefante sull'imbocco |
| cremagliera nella coda di rondine | 0.0 | 0.0 | gioco per lato mediano 0.19 mm (gioco eccessivo > 0.4) |
| vite M3 nel foro passante 3.2 | 0.2 | – | va ripassato con punta da 3.2 |
| vite M3 nel foro di rotazione 3.3 | 0.0 | – |  |
| variante horn_len 33.5 | 0.1 | – |  |
| variante horn_len 34.0 | 0.1 | – |  |
| variante clr_pocket 0.25 (SG90 guance) | 22.4 | – |  |
| variante clr_pocket 0.3 (SG90 guance) | 10.4 | – |  |
| variante clr_pocket 0.3 + 0.3 sul lato del ponte (SG90 guance) | 0.0 | – |  |
| variante clr_pocket 0.3 (SG90 piano pinza) | 0.0 | – |  |
| variante clr_pocket 0.3 (SG90 torre base) | 0.0 | – |  |

## Raccomandazioni (in ordine di sezione)

1. Braccio: due nervature 2.5 x 6 mm sui bordi della faccia lato servo (x 24…74, la canalina resta in mezzo): I fuori piano da 1060 a 1060 mm⁴. Ricontrollare con cad/check_grid.sh.
2. Guance torretta: fazzoletti esterni da 25 a 50 mm di altezza e profondi 12 (stanno a x ±24, fuori dal servo).
3. Gomito: mozzo esterno d12 x 8 mm sul braccio attorno al foro E (foro lungo 14 invece di 6.5) e perno E da 4 mm (vite M4 o spina rettificata): con le due modifiche sopra la freccia in home scende da 5.5 a 4.4 mm.
4. Strutturale vero: il rimedio di fondo è eliminare l'eccentricità (braccio a forcella con una seconda piastra oltre il piano della biella, perno E in doppio taglio). Tutte le cedevolezze del gomito scalano con Δy².
5. lim_e minimo da 20° a 35°: perde 10 mm di sbraccio ma divide per ~3 forza nella biella e sensibilità (1/sin²e).
6. Dito ganascia: stem_t 3.5 → 6 mm e tab[1] 4 → 5 mm (taglio interlaminare 5.6 → 5.6 MPa).
7. Perno E in acciaio d4 (vite M4x45 o spina) con fori 4.2/4.3; in alternativa M3 classe 12.9 a gambo parziale.
8. A: integrare il distanziale d7 nella manovella (mozzo stampato pieno alto 4.9 mm) e crank_t 4 → 6 mm al perno.
9. A, B, P1, U: frenafiletti medio sul dado incassato (ruotano: un dado normale si svita).
10. U: M3x8 invece di M3x6 (oggi impegna ~1.4 mm, meno di 3 filetti); B: M3x10 invece di M3x8.
11. Viti a gambo parziale (ISO 4762) o boccole in ottone 4/3 nei fori che ruotano, per non limare il PLA col filetto.
12. Alberi SG90: aggiungere un appoggio esterno al braccio (anello coassiale d≈36 sulla guancia −Y che fa da boccola al mozzo, o un perno folle M3 dalla guancia +Y attraverso la manovella), oppure passare a MG90S (cuscinetto sull'uscita).
13. wrist.scad, rack(): aggiungere il collo come nel provino, nel 2D della coda di rondine `translate([-(dt_top / 2 - clr_slide), -clr_slide - 0.01]) square([dt_top - 2 * clr_slide, clr_slide + 0.02]);` (largo 7.4 mm, passa nella fessura da 8).
14. Ganasce: stampare la cremagliera in piano (fianchi verticali) separandola dal dito, con 2 viti M3x8 e dado nel gambo; in alternativa tenerle di fianco ma a layer 0.12 (gradino 0.11 mm) e bl 0.15 → 0.25.
15. Gioco del dente 0.37 mm: va bene per una pinza; se serve precisione, clr_slide 0.3 → 0.2 dopo il provino.
16. Grasso al PTFE/silicone sulle code di rondine: μ 0.35 → 0.15 porta la presa da 1.9 a 3.1 N per dito.
17. rack_len 40 → 50 mm (e y_half 36 → 41) se c'è spazio: rendimento 0.40 → 0.44.
18. clr_slide: tenere 0.3 finché il provino non dice altro; sotto 0.2 le creste dei layer della gola fanno impuntare.
19. snap_hook 0.4 → 0.8 mm nella base (solo per la culla ESP32): sovrapposizione 0.6, ε 0.20%, P(non trattiene) da 0% a 0.0%.
20. Raccordo r 1 mm al piede della lamella (oggi spigolo vivo su un piano di layer).
21. Staffa → piano pinza: interasse viti 5 → 7.5 mm (x_back + 2.5 e x_back + 10, flangia della staffa 12 → 14 mm), oppure una vite sola M3 con dado + perno di centraggio.
22. Biella motrice: occhio d8 → d9 attorno al dado di A, o sede ruotata di 30° (lato piatto verso l'estremità).
23. Coda del braccio e manovella: orecchie delle viti del coperchio r 4 → 5 mm (parete al dado da 0.6 a 1.6 mm).
24. Coppia di serraggio delle autofilettanti nel PLA: a mano, fermarsi al contatto + 1/8 di giro.
25. Riposo: non lasciare il braccio alimentato in posa per ore con payload; a fine lavoro `estop` o una posa di parcheggio appoggiata (pinza sul tavolo) così nessun servo tiene coppia.
26. Guance: fori di aerazione o 2 mm di distanza tra cassa del servo e PLA sui lati lunghi (la finestra ora è a contatto).
27. Se si vuole lasciare il braccio in posa a lungo, stampare torretta e braccio in PETG o PLA+ ricotto (HDT 60 → 80+ °C).
28. Pinza: non chiudere a stallo su un oggetto per ore (dito in taglio interlaminare): il firmware dovrebbe aprire di 0.5 mm dopo il contatto.
29. horn_len 32.5 → 33.5: con squadrette fino a 33.5 mm la tasca da 32.9 non le prende nel 0% dei casi (0.1% con 33.5); la tasca un po' lunga non costa nulla, la squadretta è centrata dall'albero.
30. Avvitare la squadretta anche nella torretta e nella manovella (2 viti autofilettanti nei fori delle punte, come nel braccio): toglie il gioco angolare della tasca (mediano 1.3°, sulla base ±1.4 mm al TCP in home).
31. Finestre SG90: clr_pocket 0.2 → 0.3 per i servo (guance 10% → 10%, torre base 0% → ~0%), e nelle guance altri 0.3 mm sul lato alto (ponte che cala) → 0%. Piano pinza: smusso 0.5 x 45° sul lato del piatto o compensazione del piede d'elefante nello slicer.
32. Sedi dei piombi della manovella: smusso 0.4 x 45° sull'imbocco (lato piatto) contro il piede d'elefante.
33. Corona della base: grasso al PTFE e appoggio su un anello più piccolo; l'attrito ferma la torretta prima del bersaglio dal lato da cui arriva (errore bimodale ±0.5–1° → ±2–3 mm al TCP). In firmware: arrivare sempre dallo stesso verso (piccolo sovra-corsa e ritorno) dimezza la ripetibilità della base.
34. Ripetibilità della spalla in home: col braccio verticale la coppia di gravità è nulla con qualunque contrappeso, quindi il giunto si ferma in un punto a caso della banda morta e dei giochi. Un elastico o una molla a torsione tra braccio e torretta da ~0.1 kg·cm costanti lo tiene sempre appoggiato dallo stesso lato.

## Cosa misurare per tarare i modelli

- Freccia in `home` con 50 g in pinza (calibro a corsoio dal tavolo), poi la stessa premendo a mano il gomito verso la guancia
  del servo: la differenza è la parte fuori piano (braccio + guancia + albero) che il modello stima.
- Gioco del gomito a servo spento: spostamento della punta dell'avambraccio tra i due fine-gioco.
- Temperatura della cassa del servo gomito dopo 10 min in `home` con 50 g (dito o termometro IR).
- Larghezza della scheda ESP32 e lunghezza delle squadrette in casa: aggiornano subito le probabilità di §5 e §8.

## Limiti

Modelli a travi e lastre con rigidezze di bordo stimate, non FEM. La freccia elastica è lineare: oltre qualche grado di rotazione
dell'avambraccio (sbraccio, ripiegato) indica una cedevolezza eccessiva, non un valore esatto. Le distribuzioni del Monte Carlo
sono tipiche di una FDM tarata e di SG90 cloni; il provino di `cad/test/tolerance_coupon.scad` le sostituisce con misure.
Tempo di calcolo: 105 s.

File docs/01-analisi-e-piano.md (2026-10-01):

# Analisi carichi, cinematica e scelte di progetto (rev. C)

Vincoli:
- solo gli SG90 180° già in casa;
- niente alimentatore industriale;
- contrappesi con i piombi da pesca già in casa (6 × 20 g, a oliva 22.2 × 13.7 mm);
- tutto in PLA sulla Anycubic Kobra S1 (250 × 250 × 250).

Numeri riproducibili:
- `python3 calc/torque.py` per le coppie, con assert sui punti di progetto;
- `cad/assembly.scad` per le collisioni, con ferramenta compresa.

## 1. Topologia

Con i servo in serie (servo gomito sul gomito), la spalla di un SG90 porta tutta la catena **più** il servo del gomito a leva piena, e va sotto SF 1.5 già con link da 80 mm.

Si usa quindi la **topologia parallela** (famiglia MeArm/EEZYbot):
- **Servo spalla e servo gomito sulla torretta**, coassiali, uno per guancia.
- **Parallelogramma di comando:** il gomito è mosso da manovella e biella motrice.
  - La manovella ha la stessa lunghezza della leva posteriore dell'avambraccio (20 mm).
  - La biella è lunga quanto il braccio (80 mm).
  - L'angolo del servo gomito è quindi l'angolo **assoluto** dell'avambraccio (phi).
- **Due parallelogrammi passivi di livellamento** tengono la pinza sempre orizzontale:
  - montante fisso G → biella 1 → triangolo al gomito;
  - triangolo al gomito → biella 2 → staffa del polso.
- **Lavoro virtuale:**
  - T_gomito = g·Σ mᵢ·dᵢ, con i momenti della catena dell'avambraccio attorno al gomito.
  - T_spalla = g·(m_braccio·d + M_catena·L1): la catena pesa sulla spalla solo come massa al gomito.
- **Contrappesi:**
  - Piombi sulla **coda della manovella** (arco di 6 sedi a r = 43 mm, se ne riempiono le 2 centrali) e sulla **coda del braccio** (4 sedi in fila a 30 mm, tutte piene).
  - Coda e segmento ruotano insieme, quindi la compensazione vale a ogni angolo.
  - La manovella gira sull'asse della torretta: il suo contrappeso non carica la spalla.

## 2. Giunti e geometria

| Giunto | Servo | Range | Riferimento a 1500 µs |
|---|---|---|---|
| J1 base (yaw) | SG90 in torre, sotto la torretta | −90 … 90° | braccio in avanti |
| J2 spalla (th2, assoluto) | SG90 guancia −Y | 20 … 160° | braccio verticale |
| J3 gomito (phi, assoluto) | SG90 guancia +Y, via manovella | −70 … 70° | avambraccio orizzontale |
| vincolo | — | 35 ≤ th2 − phi ≤ 150 | parallelogramma non degenere, ferramenta libera |
| J4 pinza | SG90 capovolto sulla pinza | 0 … 59 mm | 29.5 mm |

Dimensioni:
- L1 = L2 = 80 mm.
- TCP (centro delle dita) 42 mm avanti e 24 mm sotto il perno del polso.
- Sbraccio orizzontale **188 mm** dall'asse della spalla, con il vincolo th2 − phi ≥ 35° (sotto, il parallelogramma amplifica la cedevolezza: [05-verifiche.md](05-verifiche.md)).
- Asse della spalla a 102 mm dal tavolo.
- Polso roll escluso: servirebbe un contrappeso che non c'è.

I limiti vengono dai piani delle parti lungo l'asse della spalla, compresi teste delle viti e dadi. Il controllo di `cad/assembly.scad` non trova collisioni su una griglia di pose che copre tutto il range, a pinza chiusa e aperta.

## 3. Coppie (SG90 = 1.6 kg·cm @4.8V dichiarati, obiettivo SF ≥ 2)

Masse dai volumi degli STL: PLA al 60% di riempimento effettivo, più servo e ferramenta.

| Configurazione | Payload | Gomito | Spalla |
|---|---|---|---|
| senza contrappeso, senza camera | 50 g | SF 1.4 ✗ | — |
| **2 piombi manovella + 4 braccio, senza camera** | **50 g** | **SF 2.6** | **SF 2.3** |
| **2 + 4 piombi, con ESP32-CAM** | **50 g** | **SF 2.2** | **SF 2.0** |
| 2 + 4 piombi, con ESP32-CAM | 30 g | SF 2.9 | SF 2.5 |

Punto di progetto: **50 g, anche con la camera**.

La pinza è livellata: ruotando l'avambraccio trasla senza ruotare, quindi pinza, carico e camera pesano sul gomito con braccio L2 e non L2 + 42 mm. Il resto del momento lo regge il montante fisso G.
La simulazione MuJoCo (`sim/dynamics`) lo conferma: le coppie a regime coincidono con il lavoro virtuale.
Il giunto che limita è la spalla. Con SG90 deboli (1.2 kg·cm) conviene restare a 30 g, oppure tenere v ≤ 0.7.

Base, pinza e corrente:
- **Base:** 0.18 kg·cm di inerzia a 10 rad/s² più 0.45 kg·cm di attrito della corona PLA su PLA, **SF 2.5**. Con il grasso l'attrito cala.
- **Pinza:**
  - pignone m1 z32 (r = 16 mm): la corsa di 59 mm richiede **106°** di servo;
  - forza per dito 4.9 N contro 1.6 N richiesti (50 g, μ 0.3, SF 2).
- **Corrente:** stallo cumulativo 4 × 0.75 A = 3 A. Caricatore USB 5V ≥ 3A.

## 4. Scelte che contano

- **L'albero del servo trasmette solo coppia.** I carichi radiali restano sotto circa 1.5 N, la classe dei bracci MeArm.
  I perni sono viti M3 con autobloccanti "a scorrimento" e distanziali stampati.
- **Ferramenta nei piani giusti.** Dove una testa o un dado finirebbe nel piano di un'altra biella si usano dadi incassati: A nella biella motrice, B nella piastra R, P1 e U nel triangolo.
  Il controllo collisioni modella ogni testa, dado e distanziale.
- **Pinza senza pareti.** Le cremagliere scorrono su code di rondine, lo stesso profilo del provino, che le guidano in tutto tranne lo scorrimento.
  È l'alleggerimento che ha portato la pinza da ~60 a ~40 g.
- **PLA:**
  - è più rigido del PETG (E 3.5 contro 2.1 GPa);
  - è più preciso su ingranaggi e sedi;
  - con tensioni sotto 2 MPa lo scorrimento viscoso non conta;
  - gli incastri a scatto sono dimensionati per una deformazione ≤ 2%.
- **Sicurezza sul device.** Il firmware applica limiti, vincolo, clamp dei µs, rampe, watchdog ed E-stop, qualunque cosa mandi il browser.

## 5. Elettronica

Vedi [02-cablaggio.md](02-cablaggio.md):
- pilotaggio diretto dai GPIO dell'ESP32 (33, 25, 26, 27, con LEDC a 50 Hz);
- 5V dei servo dal caricatore USB tramite WAGO;
- logica su una porta separata, con massa comune;
- pull-down da 10 kΩ sui segnali.

## 6. Software

Vedi [03-protocollo.md](03-protocollo.md): frame, FK, IK in forma chiusa, taratura, WebSocket.
- **Firmware:** PlatformIO con arduino-esp32 2.0.17, planner trapezoidale sincronizzato, test nativi.
- **Web app:** Vite + Three.js, digital twin con gli STL reali, FK, IK con gizmo, waypoint e sequenze, taratura, modalità simulazione.

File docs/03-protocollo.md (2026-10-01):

# BRACCIO — Cinematica, taratura e protocollo (contratto firmware ↔ web app)

Unica fonte delle quote meccaniche: `cad/params.scad`. I numeri qui sotto ne sono una copia.
Se cambiano là, vanno aggiornati qui, in `firmware/src/config.h` e in `web/src/robot.js`.

## 1. Giunti (unità di giunto)

| # | Nome | Simbolo | Unità | Limiti default | Riferimento (q_ref → 1500 µs) |
|---|---|---|---|---|---|
| 0 | base (yaw) | q1 | ° | −90 … 90 | 0 (braccio in avanti, +X) |
| 1 | spalla | th2 | ° assoluti dall'orizzontale | 20 … 160 | 90 (braccio verticale) |
| 2 | gomito | phi | ° assoluti dall'orizzontale (angolo avambraccio) | −70 … 70 | 0 (avambraccio orizzontale) |
| 3 | pinza | g | mm di apertura | 0 … 59 | 29.5 |

**Vincolo del parallelogramma** (in aggiunta ai limiti): `35 ≤ th2 − phi ≤ 150`. Limiti e vincolo vengono dai piani delle parti e dalla ferramenta, verificati con `cad/assembly.scad`.
Un target fuori vincolo **viene rifiutato** (messaggio `err`), mai "aggiustato" in silenzio.

Il servo del gomito sta sulla torretta e muove la manovella. L'angolo della manovella è psi = phi + 180,
quindi **il servo gomito comanda direttamente phi**: la mappatura resta lineare come per gli altri giunti.

## 2. Frame e cinematica diretta (mm, gradi)

Parametri: `base_h = 40` (tavolo → faccia inferiore torretta), `sh_h = 62` (→ asse spalla), `L1 = 80`, `L2 = 80`,
`L3 = 42` (perno polso → centro dita, orizzontale), `tcp_dz = −24` (quota del centro dita rispetto al perno polso),
`crank_r = 20`, `lev_r = 20`, `lev2_r = 30`.
`L3` e `tcp_dz` sono provvisori finché la pinza non è finita: la web app li legge da `rig.json` (`params`), che ha la precedenza sui default.

- Mondo: origine sul tavolo nell'asse di yaw, **Z in alto**, X in avanti con q1 = 0.
- Frame yaw: `Tz(base_h) · Rz(q1)`.
- Nel frame yaw:
  - `O = (0, 0, sh_h)` è l'asse della spalla (lungo Y);
  - `u(a) = (cos a, 0, sin a)`;
  - `E = O + L1·u(th2)` è il gomito;
  - `W = E + L2·u(phi)` è il perno del polso.
- **TCP** = `W + (L3, 0, tcp_dz)`: la pinza è livellata e sempre orizzontale. Nel mondo:
  ```
  r = L1 cos th2 + L2 cos phi + L3
  x = r cos q1,  y = r sin q1,  z = base_h + sh_h + L1 sin th2 + L2 sin phi + tcp_dz
  ```

### Frame delle parti (per il digital twin)

Ogni parte STL è modellata in un frame locale. Il posizionamento segue la semantica di OpenSCAD:
`P(p, a) = T(p) · Ry(−a) · Rx(−90)`, dove `Ry(b)` è la rotazione destrorsa attorno a Y.
Così la X locale punta nella direzione `u(a)` e la Z locale va su +Y del mondo.
`y` è il piano della parte lungo l'asse della spalla, letto da `rig.json`. `psi = phi + 180`.

| Parte | Frame | Trasformazione |
|---|---|---|
| base | mondo | identità |
| turret | yaw | identità |
| upper_arm | yaw | `P(O + (0,y,0), th2)` |
| crank | yaw | `P(O + (0,y,0), psi)` |
| drive_rod | yaw | `P(O + crank_r·u(psi) + (0,y,0), th2)` |
| lev_rod | yaw | `P(O + lev_r·u(180) + (0,y,0), th2)` (perno fisso G sulla torretta) |
| forearm | yaw | `P(E + (0,y,0), phi)` |
| lev_link | yaw | `P(E + (0,y,0), 0)` (triangolo al gomito: orientamento costante) |
| lev_rod2 | yaw | `P(E + lev2_r·u(90) + (0,y,0), phi)` |
| wrist | yaw | `P(W + (0,y,0), 0)` (staffa + corpo pinza, livellato; y = 0) |
| jaw_l / jaw_r | wrist | traslazione lungo la Z locale di `+g/2` / `−g/2` |

`web/public/models/rig.json` (lo genera il CAD):

```json
{ "params": { "base_h": 40, "sh_h": 62, "L1": 80, "L2": 80, "L3": 42, "tcp_dz": -24,
              "crank_r": 20, "lev_r": 20, "lev2_r": 30 },
  "parts": [ { "name": "upper_arm", "file": "upper_arm.stl", "y": -25.4, "color": "#e8e8e8" } ] }
```

Una parte senza `file` o con file mancante viene disegnata come segnaposto (box) nello stesso frame.

Piani `y` attuali: upper_arm −25.4, crank 18.1, drive_rod 9.0, lev_rod −3.0, forearm −18.8, lev_link −7.0,
lev_rod2 −10.5, wrist 0.

## 3. Cinematica inversa (forma chiusa)

Input: TCP `(x, y, z)` nel mondo. Output: `q1, th2, phi`, con la configurazione a gomito alto.

```
q1  = atan2(y, x)
r   = hypot(x, y) − L3
zz  = z − base_h − sh_h − tcp_dz
c   = (r² + zz² − L1² − L2²) / (2·L1·L2)        // = cos(th2 − phi)
se |c| > 1 → irraggiungibile
e   = acos(c)                                    // e = th2 − phi, in [0, 180]
th2 = atan2(zz, r) + atan2(L2·sin e, L1 + L2·cos e)
phi = th2 − e
```

La soluzione va poi validata contro i limiti e il vincolo. Se non passa, l'UI la segnala e non manda nulla.
Test obbligatorio: FK(IK(p)) = p entro 0.01 mm su una griglia di punti raggiungibili, e IK(FK(q)) = q.

## 4. Taratura (per giunto, salvata in NVS dell'ESP32)

```
us = ref_us + k · (q − q_ref)          clamp finale del segnale a [500, 2500] µs
```

| Campo | Significato | Default J0 / J1 / J2 / J3 |
|---|---|---|
| `ref_us` | impulso al riferimento | 1500 / 1500 / 1500 / 1500 |
| `k` | µs per unità, il **segno** dà il verso | 11.11 / 11.11 / 11.11 / 19.89 |
| `q_ref` | unità di giunto al riferimento | 0 / 90 / 0 / 29.5 |
| `min`, `max` | limiti di giunto | vedi §1 |

- SG90: 500–2500 µs corrispondono a 180°, cioè 11.11 µs/°.
- Pinza: pignone m1 z32 (r = 16 mm), apertura = 2·r·Δθ, quindi 1 mm di apertura = 1.79° = 19.89 µs.
  La corsa completa di 59 mm richiede 106° di servo.

**Procedura di taratura (UI):**
1. `raw` porta il servo a un impulso esplicito.
2. Si monta la squadretta con il giunto nella posa di riferimento, oppure si regola l'impulso finché il giunto è nella posa di riferimento, e si salva `ref_us`.
3. Si porta il giunto a un secondo angolo noto per ricavare `k` (e il segno).
4. Si verificano i limiti.

## 5. Moto (firmware)

- Loop di controllo a 50 Hz, uno per frame servo.
- Profilo **trapezoidale sincronizzato**: tutti i giunti partono e arrivano insieme, scalati sul giunto più lento.
- Limiti: `vmax` 90 °/s (pinza 60 mm/s), `amax` 180 °/s² (pinza 120 mm/s²), moltiplicati per il fattore `v` ∈ (0, 1] del comando.
- Un nuovo `move` durante il moto riparte dalla posizione e velocità correnti, senza fermarsi.
- **Bordi morbidi:** vicino ai limiti di giunto e al vincolo th2 − phi il planner frena in tempo, invece di fermare il giunto di colpo. L'ultima difesa interviene a 0.01 oltre i bordi.
- **Tolleranza 0.001** su limiti e vincolo: un target sul bordo, arrotondato a 0.01 dal browser, non viene rifiutato per errore di float.
- **Il twin della web app (`web/src/motion.js`) è una copia riga per riga del planner del firmware**: scarto ≤ 0.004° su 6000 scenari (`sim/software`).
- **La sicurezza sta sul device:** limiti, vincolo del parallelogramma e clamp dei µs sono applicati sempre, qualunque cosa mandi il browser.
- Boot:
  - PWM **non** agganciato: servo senza coppia, linee tenute basse dai pull-down.
  - `enable` aggancia il PWM alla posa `home` salvata in NVS (default `[0, 90, 0, 30]`), **un servo ogni 200 ms**: picco di spunto ~1.7 A invece di ~2.7 A.
    Durante l'aggancio, per circa 0.6 s, `move` e `raw` rispondono `err` "enable in corso". Il braccio va lasciato vicino a `home` prima di spegnere.
- Watchdog: se l'ultimo client WebSocket si disconnette durante un moto → `stop` (decelera e tiene la posizione).
- `estop`: sgancia subito il PWM (servo liberi), mette `enabled = false` e **scarta i comandi ancora in coda**, così niente di arrivato prima viene eseguito dopo.

## 6. Rete

- WiFi:
  - prova la rete di casa per 10 s, con credenziali in `firmware/include/secrets.h` (non versionato; esiste `secrets.example.h`);
  - se fallisce, crea l'**AP `BRACCIO`** con password `braccio-arm`, IP 192.168.4.1.
- mDNS: `braccio.local`.
- HTTP porta 80:
  - `GET /` serve la web app da LittleFS, con file `.gz` precompressi;
  - `GET /api/info` risponde `{fw, ip, mode}`.
- WebSocket su `ws://<host>/ws`, messaggi JSON di testo.

### Browser → ESP32

| Messaggio | Effetto |
|---|---|
| `{"t":"move","q":[q1,th2,phi,g],"v":0.5}` | moto sincronizzato verso il target (validato); `v` assente = 0.5, di tipo sbagliato = rifiutato |
| `{"t":"stop"}` | decelera e tiene la posizione |
| `{"t":"estop"}` | PWM sganciato subito |
| `{"t":"enable"}` | aggancia il PWM alla posa corrente o `home` |
| `{"t":"raw","j":1,"us":1500}` | taratura: impulso diretto a un giunto (clamp 500–2500), solo se enabled e fermo; rifiutato se viola il vincolo th2 − phi |
| `{"t":"cal_get"}` | risponde `cal` |
| `{"t":"cal_set","cal":[{ref_us,k,q_ref,min,max}×4]}` | aggiorna la taratura in RAM; `min`/`max` non possono uscire dai limiti meccanici |
| `{"t":"cal_save"}` | salva la taratura in NVS |
| `{"t":"home_set"}` | salva la posa corrente come `home` |

### ESP32 → browser

| Messaggio | Quando |
|---|---|
| `{"t":"state","q":[..4],"target":[..4],"us":[..4],"moving":true,"enabled":true}` | 20 Hz |
| `{"t":"cal","cal":[..4],"home":[..4]}` | risposta a `cal_get` e dopo `cal_set` |
| `{"t":"err","msg":"fuori vincolo: th2-phi=12"}` | comando rifiutato |
| `{"t":"hello","fw":"0.1.0","mode":"sta|ap"}` | alla connessione |

### Pin (vedi 02-cablaggio.md)

J0 base **GPIO33**, J1 spalla **GPIO25**, J2 gomito **GPIO26**, J3 pinza **GPIO27**. PWM a 50 Hz tramite LEDC.

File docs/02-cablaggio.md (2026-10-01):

# BRACCIO — Schema di cablaggio (rev. B: GPIO diretti, zero saldature)

Niente PCA9685: i 4 SG90 sono pilotati dal PWM hardware (LEDC) dell'ESP32, a 50 Hz con risoluzione di 14 bit.
Il 5V dei servo arriva ai WAGO direttamente dal caricatore e non passa mai né dalla breadboard né dall'ESP32.

## Schema

```
            CARICATORE USB 5V ≥ 3A (2 porte)
             │ porta A                    │ porta B
             │ cavo USB normale           │ cavo USB sacrificato: taglia il connettore lato device,
             ▼                            │ spela 8 mm. Rosso = +5V, nero = GND (verifica col tester!)
      ┌──────────────┐                    │ bianco/verde: isolali col nastro
      │  ESP32       │                    ▼
      │  DevKit V1   │          ┌───────────────────┐   ┌───────────────────┐
      │              │          │ WAGO +5V (5 poli) │   │ WAGO GND (5 poli) │
      │  GND ────────┼──────────┼───────────────────┼───┤◄── massa comune    │
      │              │          │ ◄ rosso USB       │   │ ◄ nero USB        │
      │  GPIO33 ─┐   │          │ ◄ + cond. 2200µF  │   │ ◄ – cond. (banda) │
      │  GPIO25 ─┤   │          │ ◄ rosso servo 1-2 │   │ ◄ marrone 1-2     │
      │  GPIO26 ─┤   │          └───────────────────┘   └───────────────────┘
      │  GPIO27 ─┤   │          ┌───────────────────┐   ┌───────────────────┐
      └──────────┼───┘          │ WAGO +5V (5 poli) │   │ WAGO GND (5 poli) │
                 │              │ ◄ ponte dal primo │   │ ◄ ponte dal primo │
                 ▼              │ ◄ rosso servo 3-4 │   │ ◄ marrone 3-4     │
          BREADBOARD            │ ◄ (ESP32-CAM 5V)  │   │ ◄ (ESP32-CAM GND) │
   riga segnale ── 10 kΩ ── riga GND breadboard ── GND ESP32
   riga segnale ── Dupont ── arancione servo
```

## Mappa pin

| Giunto | Servo | GPIO ESP32 | Filo servo |
|---|---|---|---|
| J1 base | SG90 | **GPIO33** | arancione |
| J2 spalla (guancia sinistra) | SG90 | **GPIO25** | arancione |
| J3 gomito (guancia destra, manovella) | SG90 | **GPIO26** | arancione |
| J4 pinza | SG90 | **GPIO27** | arancione |
| tutti | — | — | rosso → WAGO +5V, marrone → WAGO GND |

Perché questi pin:
- 33, 25, 26 e 27 sono **adiacenti sullo stesso lato** del DevKit V1, quindi il cablaggio resta ordinato.
- **Non sono pin di strapping** (0, 2, 5, 12, 15), quindi non disturbano l'avvio.
- **Non emettono impulsi al boot** come fanno 1, 3, 5, 14 e 15. Liberi per il futuro: 13, 16–19, 21–23, 32.

Livelli logici: l'ESP32 manda un segnale a 3.3V a servo alimentati a 5V. Gli SG90 lo leggono senza problemi (soglia circa 1.5–2V), quindi non serve un level shifter.

## Collegare i servo senza saldare

Il connettore dell'SG90 è femmina a 3 poli, passo 2.54.
1. Infila **3 Dupont maschio-maschio** nel connettore del servo.
2. **Arancione:** l'altra estremità del jumper va in una riga della breadboard, collegata da un altro jumper al GPIO.
3. **Rosso e marrone:** taglia l'estremità libera del jumper, spela 8 mm e infilala nel WAGO.
   I jumper Dupont (26 AWG) reggono lo stallo di un SG90 (0.75 A) su 20 cm.
4. Blocca il connettore del servo e i tre jumper con un giro di nastro, così non si sfilano quando il braccio si muove.

Un'alternativa più pulita sono le prolunghe servo da 30 cm con un'estremità tagliata: rosso e marrone vanno al WAGO, l'arancione in breadboard.

## Protezioni

| Cosa | Perché |
|---|---|
| **Massa comune** con un jumper dedicato dal pin GND del DevKit **direttamente** al WAGO GND (non dalla guida della breadboard) | Senza, il segnale PWM non ha riferimento e i servo impazziscono. È l'errore n.1. Dal jumper passa parte del ritorno dei servo (fino a 0.9 A): non deve attraversare la breadboard |
| **Condensatore 2200 µF 10–16 V low-ESR** sul bus WAGO | Copre il chopping dei servo e i fronti: senza, il 3V3 dell'ESP32 scende a 2.8 V. **Polarità**: la banda con il "–" va al GND |
| **Cavo della porta B corto e grosso**: un cavo USB-C "3A" accorciato a **30–50 cm** | È la scelta che conta di più. Con un cavo da 1 m a fili sottili la caduta arriva a 1.3 V e i servo vanno in reset (< 4 V). Prova: con un servo bloccato a mano la tensione al WAGO deve restare ≥ 4.6 V |
| **Pull-down 10 kΩ** tra ogni riga segnale e GND in breadboard | Durante il boot i GPIO sono flottanti e i servo scattano. Con il pull-down la linea resta bassa, niente impulsi, servo fermi |
| **Porte USB separate** per logica e servo | Un calo di tensione dei servo non resetta l'ESP32 |
| **Nessuna corrente servo in breadboard** | Le guide reggono circa 1 A e i contatti scaldano. In breadboard passano solo segnali e i 10 kΩ |

E-stop:
- **Software:** il firmware smette di generare gli impulsi (LEDC detach) e gli SG90 restano senza coppia.
- **Hardware:** un interruttore a levetta con morsetti a vite **a valle del condensatore**: WAGO 1 con cavo B e condensatore → interruttore → WAGO 2 con i servo. Così il condensatore resta carico e la chiusura non fa spunto.
  **Non** staccare e riattaccare il cavo B a ESP32 acceso: il condensatore scarico tira 7–9 A e resetta l'ESP32.
- **All'enable** il firmware aggancia i servo **uno ogni 200 ms**: il picco scende da ~2.7 A a ~1.7 A. Un `move` mandato nei primi ~0.6 s riceve "enable in corso".
- **Pinza:** non comandarla chiusa a 0 mm su un oggetto. In stallo pieno l'SG90 assorbe 0.7 A e in 5 minuti l'avvolgimento supera i 120 °C. Comandala alla **larghezza dell'oggetto meno ~1.5 mm** (≈ 2–3° di servo): presa sufficiente e 52 °C a regime.

## Budget corrente

| Condizione | Corrente |
|---|---|
| 4 SG90 a riposo | ~40 mA |
| Movimento con rampe (firmware) | 0.4–1.2 A |
| Caso peggiore teorico (tutti in stallo) | 4 × 0.75 = **3 A** |
| ESP32-CAM (futuro, dal bus WAGO) | picchi ~0.3 A |

→ Caricatore **5V con almeno 3 A per porta**: meglio due regolatori indipendenti, oppure due caricatori con la massa comune via jumper.
Un 2A basta per muoversi, ma non per gli stalli né per la pinza stretta: lì limita a 2.2 A e porta l'ESP32 in brownout.
I dettagli e gli scenari simulati sono in `sim/electrical/` (`python3 sim/electrical/run_all.py`).

## Checklist prima di dare corrente

1. Col tester sul cavo USB tagliato: rosso a +5V rispetto al nero. Alcuni cavi hanno colori non standard.
2. WAGO chiusi, nessun filo di rame scoperto fuori dal morsetto.
3. Condensatore con la banda "–" verso il GND.
4. GND dell'ESP32 collegato al WAGO GND.
5. Primo avvio con le **squadrette smontate**: il firmware porta i servo al centro (1500 µs), poi si montano braccio e manovella nella posizione di taratura.

## Montare l'ESP32 nella base

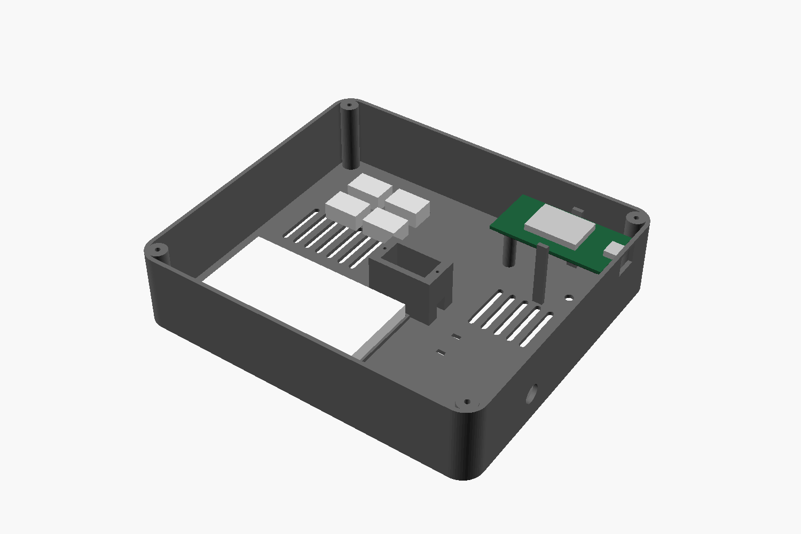
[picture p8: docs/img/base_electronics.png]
Vano elettronica


1. **Prima collega i Dupont femmina** ai pin che servono: GPIO 33, 25, 26, 27, GND e (se standalone) 5V.
   Piega i fili di 90° appena fuori dal connettore: sotto la scheda ci sono circa 6 mm.
2. Orienta la scheda con **i pin verso il basso** e la **micro-USB verso la parete posteriore** (−X), dove c'è l'apertura per il cavo.
3. Appoggiala sui due supporti ai lati corti e **premi al centro**: i due ganci sui lati lunghi scattano sul bordo del PCB.
   Per toglierla allarga leggermente i ganci con un dito.
4. Il cavo USB della porta A del caricatore entra dall'apertura della parete e alimenta l'ESP32.
   Lo stesso cavo serve per caricare il firmware.

## Percorso dei cavi e lunghezze

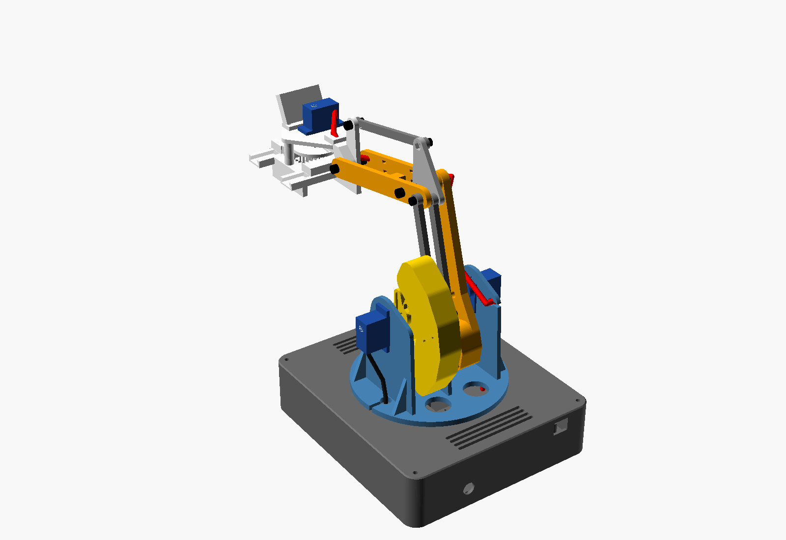
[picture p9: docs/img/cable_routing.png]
Percorso cavi


Il **fascio rosso** comprende i 3 fili del servo pinza e, se c'è, il 5V/GND della ESP32-CAM. Il percorso:
1. Dal servo pinza alla staffa del polso, con una fascetta attorno al braccetto.
2. Sulla **faccia esterna della piastra L** dell'avambraccio, con 2 fascette nelle asole.
3. Un'**ansa fuori dal gomito**, lato esterno, oltre la testa della vite.
4. Nella **canalina del braccio**, sul lato servo: il cavo si infila di taglio sotto i 3 ponticelli.
5. Nello spazio tra squadretta e guancia sinistra, con un'ansa di servizio di circa 4 cm.
6. **Asola della guancia sinistra**: il cavo entra di lato, il connettore non deve passare.
7. Giù fuori dalla guancia, poi nell'**asola del pavimento** della torretta.
8. Nella base, attraverso l'apertura centrale.
9. Ansa di yaw di circa 14 cm per i ±90° della base, poi **fascetta all'ancoraggio** nel fondo, accanto alla torre.
10. Breadboard e WAGO.

I **servo di spalla e gomito** scendono dal fondo del corpo fino alle asole del pavimento, una per lato, e poi seguono lo stesso percorso nella base.

| Cavo | Percorso misurato (pose peggiori) | Disponibile | Cosa serve |
|---|---|---|---|
| Servo pinza | 342 mm sul braccio + 141 ansa yaw + 110 nella base + 40 margine = **~63 cm** | SG90 25 cm | **2 jumper in catena**: maschio-femmina 20 cm + maschio-maschio 20 cm (o una prolunga servo da 30 cm) |
| ESP32-CAM 5V/GND | come sopra, ~63 cm | — | 3 jumper femmina-maschio in catena per filo; l'ultimo maschio va spelato nel WAGO |
| Servo spalla / gomito | 68 + 141 + 110 = **~32 cm** | SG90 25 cm + jumper 20 cm | il jumper maschio-maschio del cablaggio normale basta |
| Servo base | nella torre | SG90 25 cm | esce dall'asola in basso della torre |

Fra le pose estreme il fascio della pinza cambia lunghezza di soli **30 mm**: bastano le anse a gomito e spalla, non serve un cavo a spirale.

Fissa i giunti tra i Dupont con un giro di nastro, così non si sfilano quando il braccio si muove.

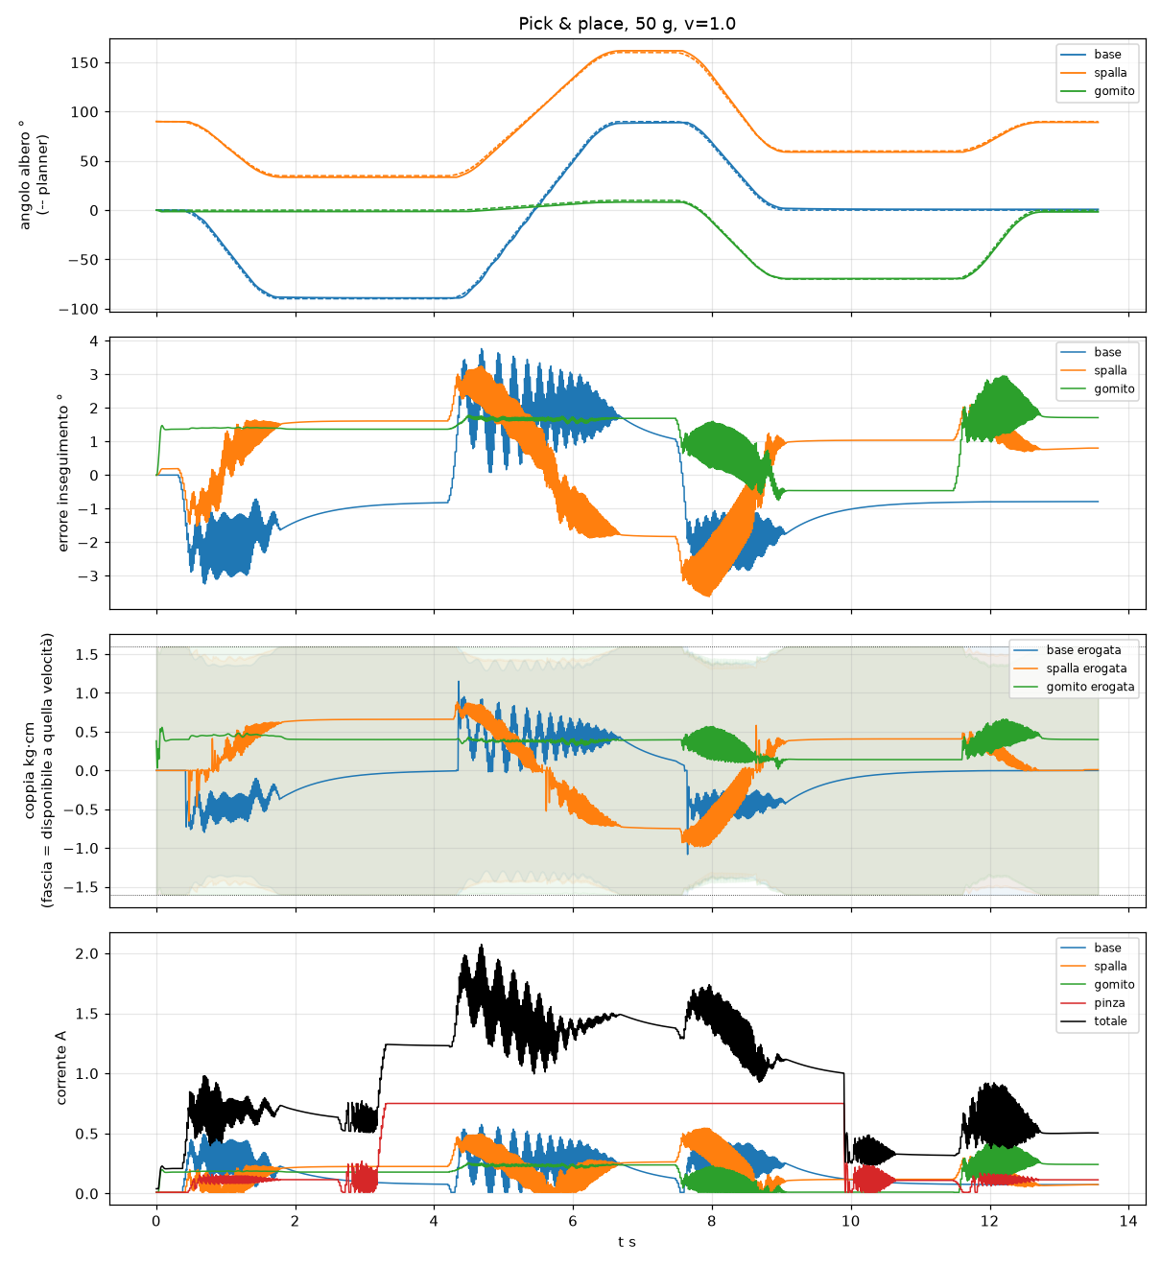
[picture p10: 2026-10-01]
sim/dynamics/fig/seq_50g_v1.0.png

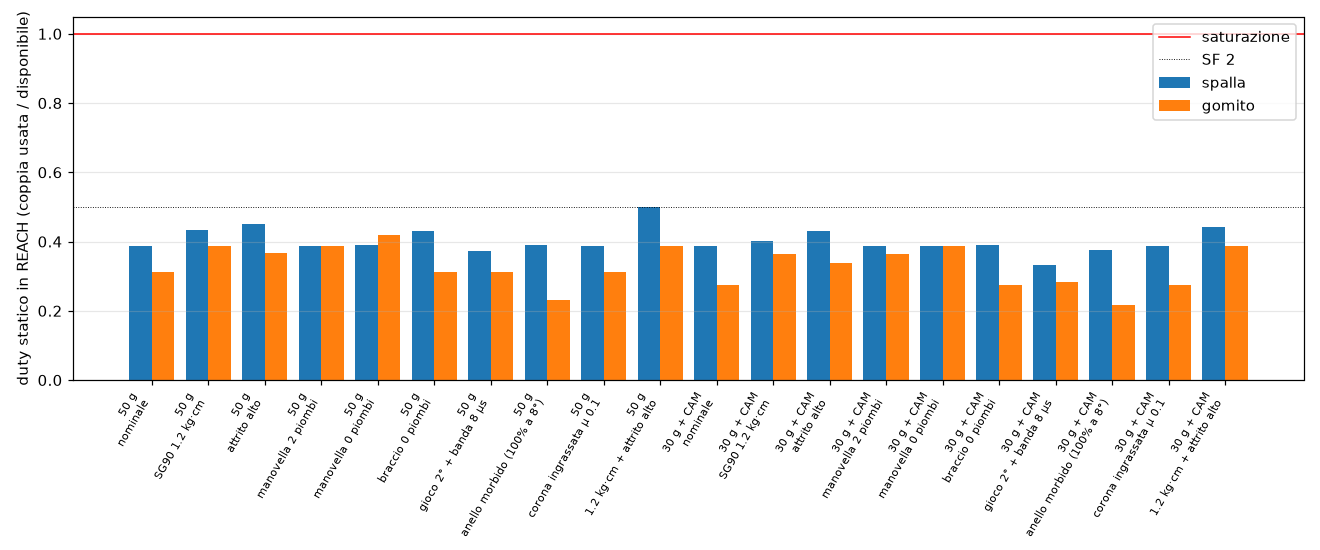
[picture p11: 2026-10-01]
sim/dynamics/fig/sensitivity.png

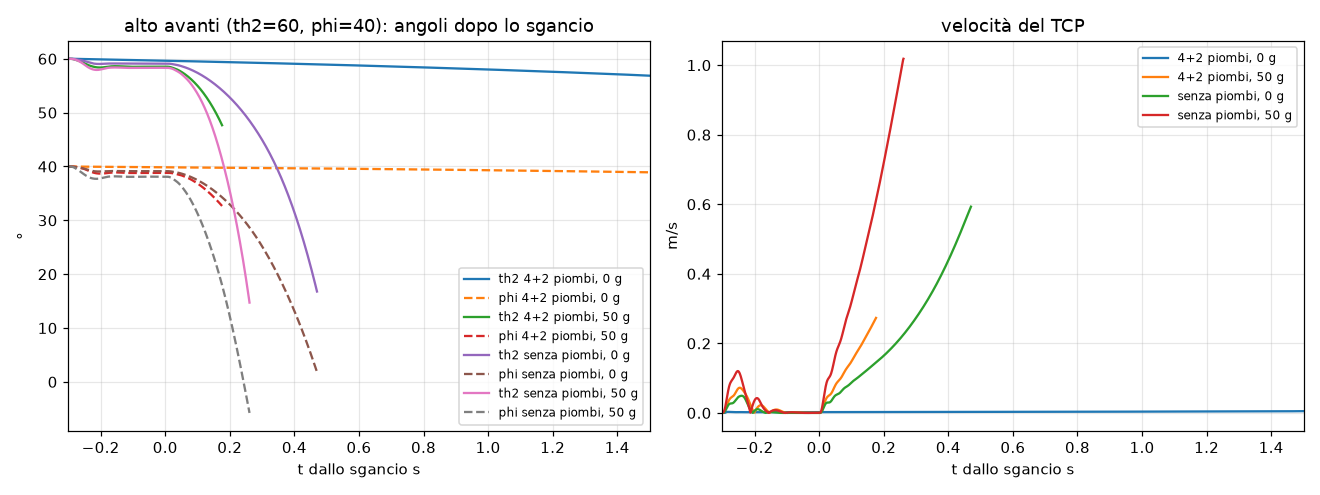
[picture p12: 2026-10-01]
sim/dynamics/fig/estop.png

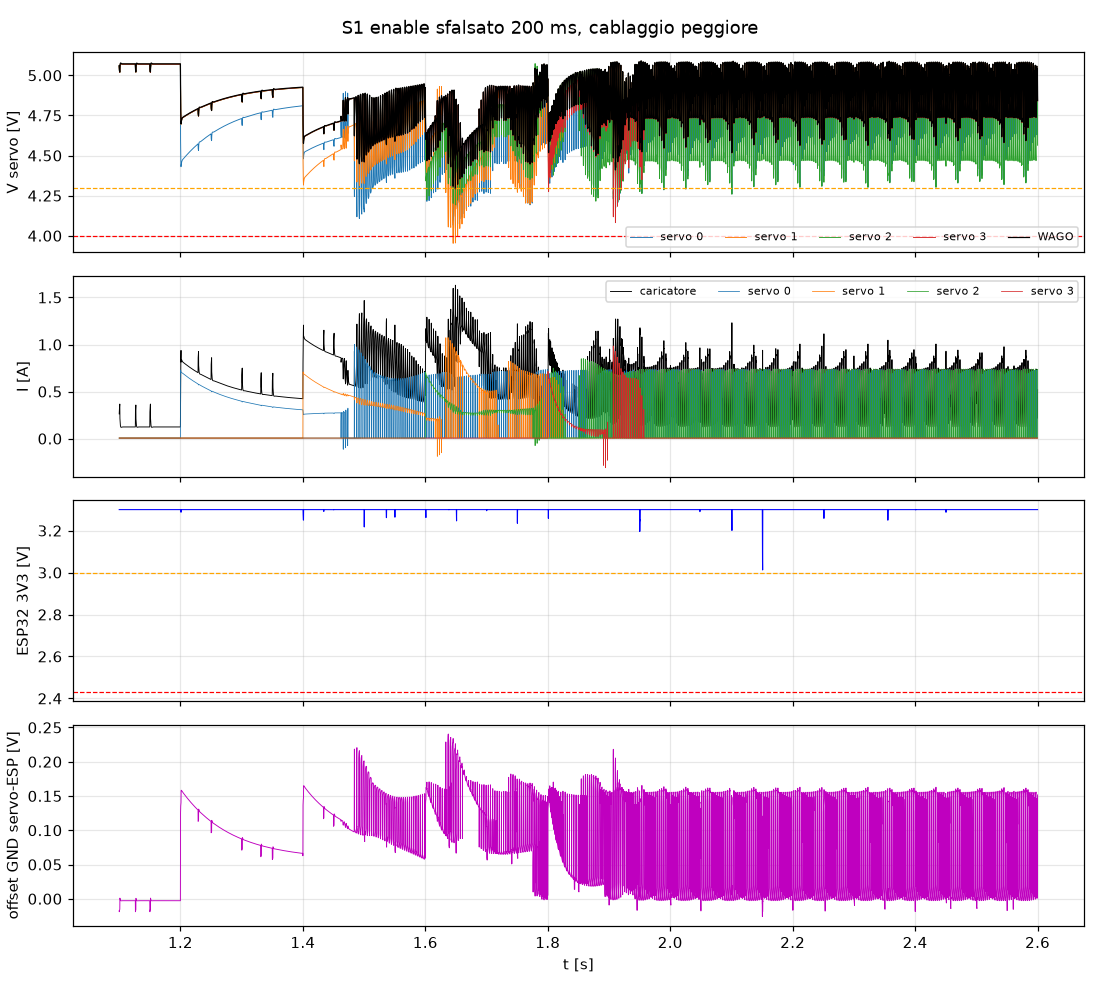
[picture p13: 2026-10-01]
sim/electrical/out/s1_enable_sfalsato.png

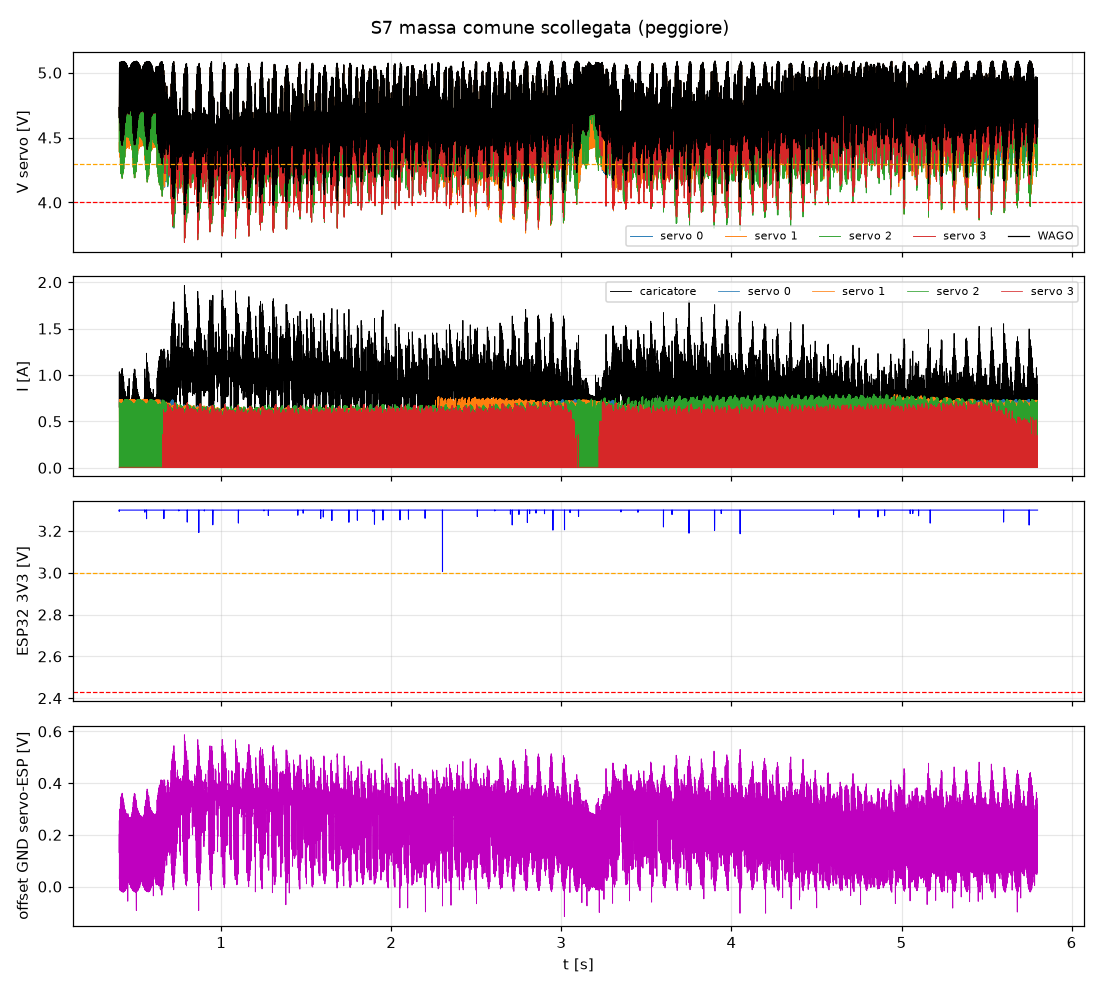
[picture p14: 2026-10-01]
sim/electrical/out/s7_senza_massa.png

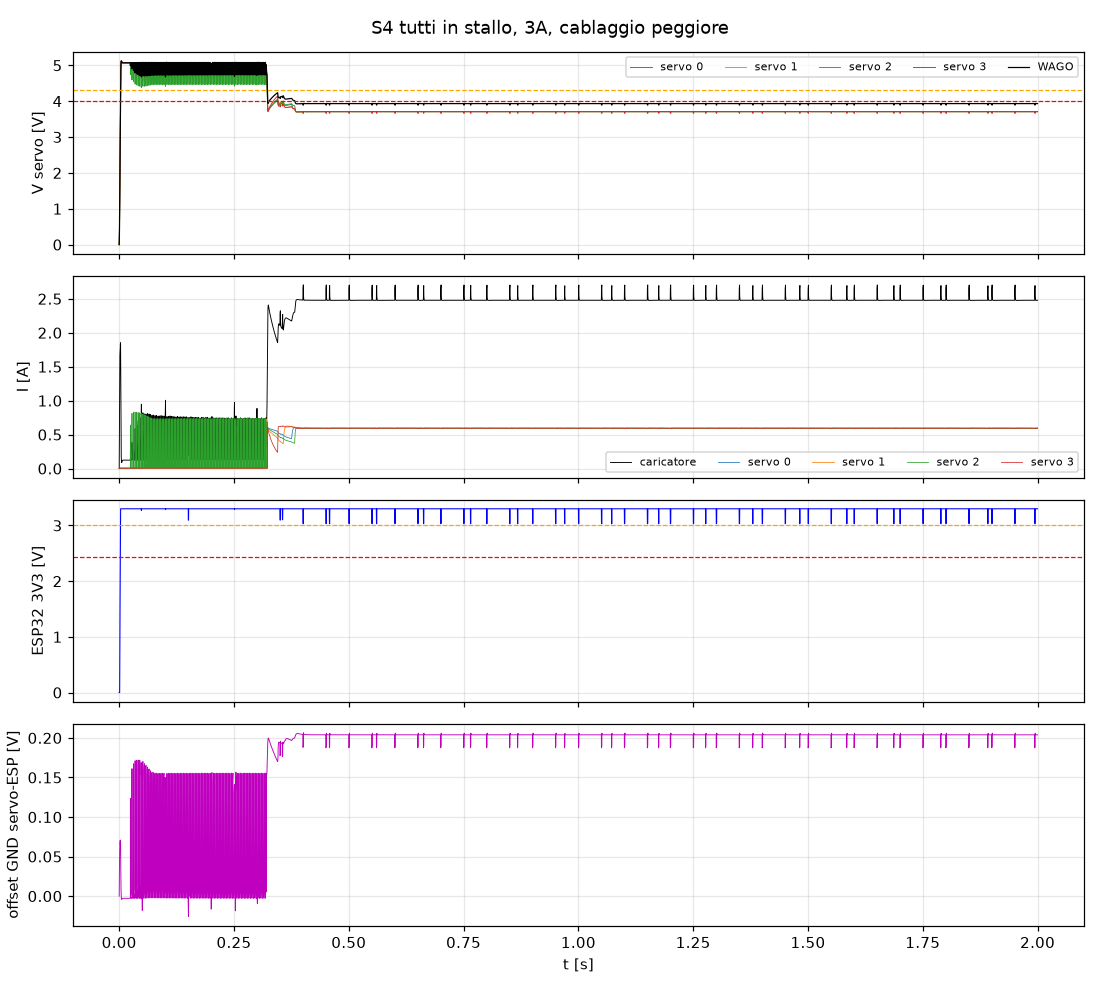
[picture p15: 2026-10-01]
sim/electrical/out/s4_stallo_3A.png

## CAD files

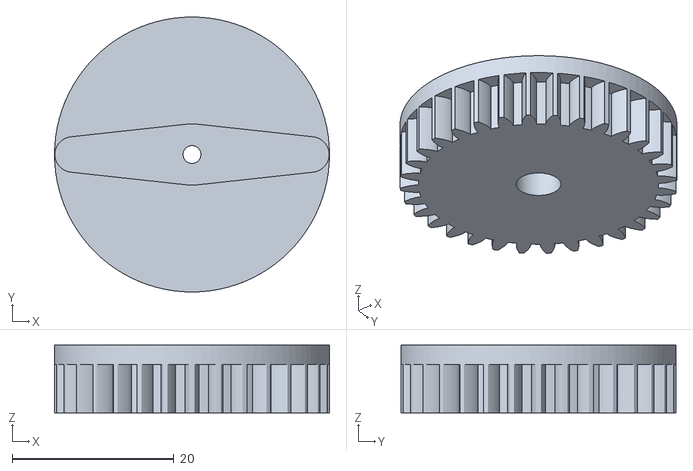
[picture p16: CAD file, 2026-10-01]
cad/stl/18_gripper_pinion.stl
34.0 x 34.0 x 8.40

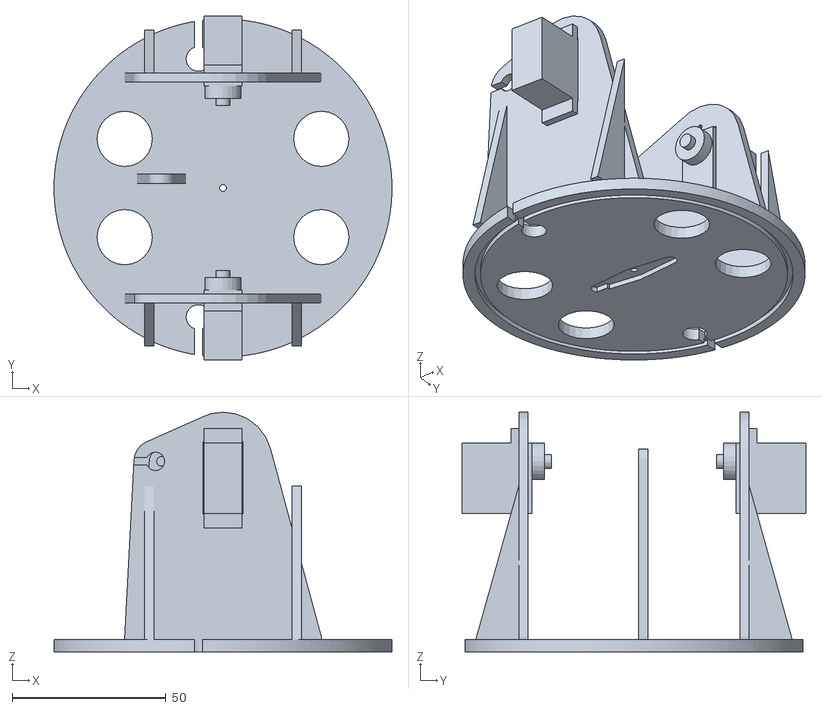
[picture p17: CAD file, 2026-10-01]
web/public/models/turret.stl
110.0 x 111.8 x 78.0

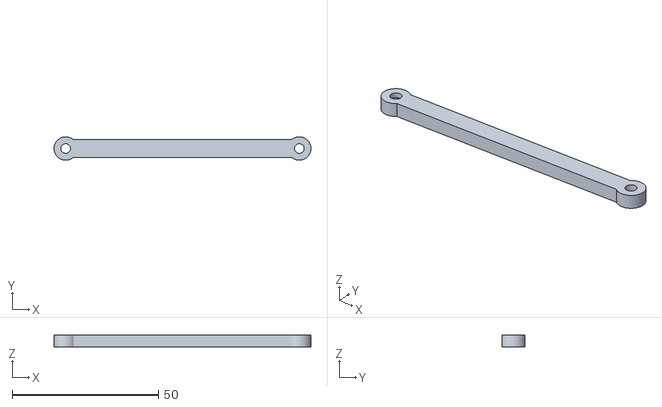
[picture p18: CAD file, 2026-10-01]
cad/stl/09_drive_rod.stl
88.0 x 8.00 x 4.00

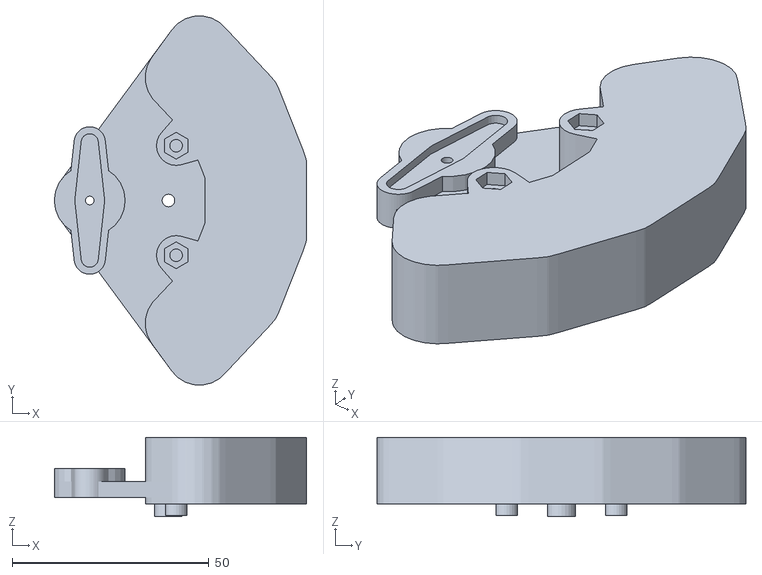
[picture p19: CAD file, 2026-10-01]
web/public/models/crank.stl
64.1 x 93.8 x 20.2

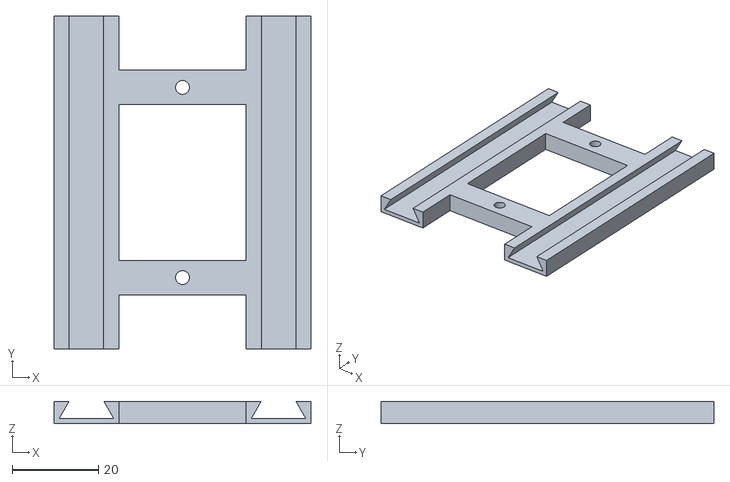
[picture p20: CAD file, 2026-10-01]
cad/stl/17_gripper_base_plate.stl
59.5 x 77.0 x 5.20

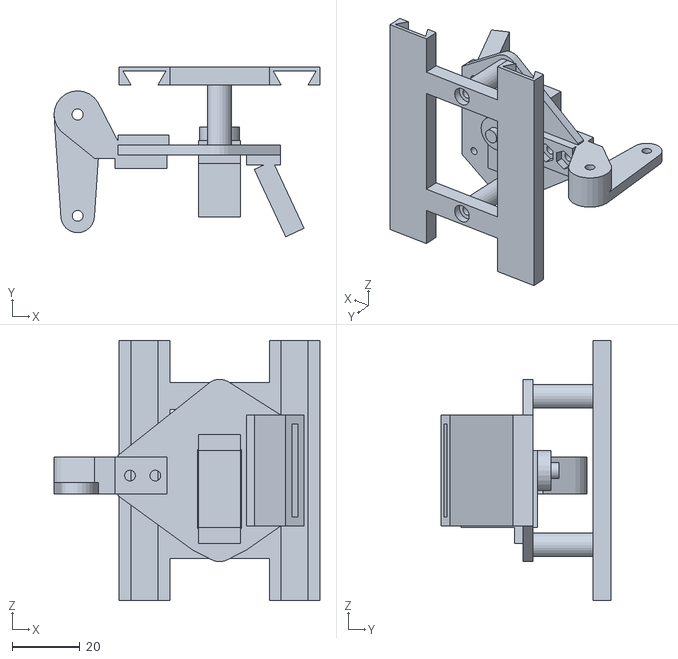
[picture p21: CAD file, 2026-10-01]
web/public/models/wrist.stl
78.7 x 50.2 x 77.0

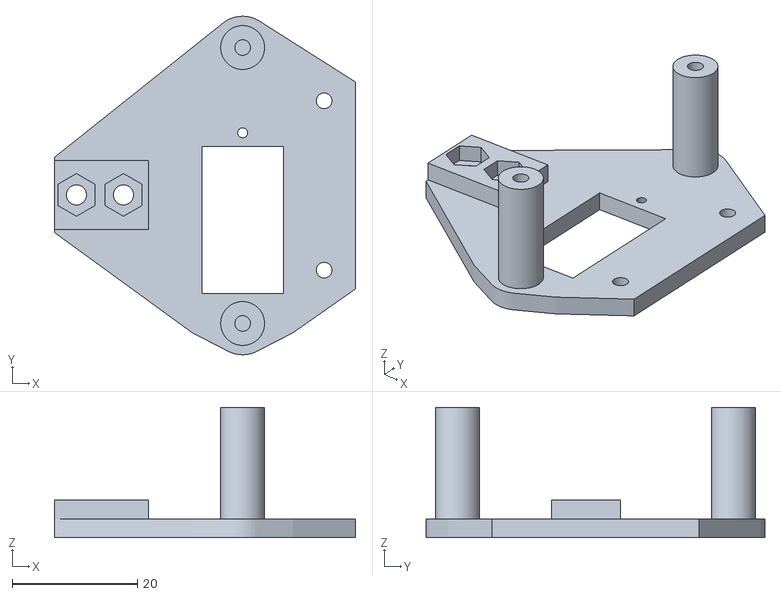
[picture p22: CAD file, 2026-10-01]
cad/stl/16_gripper_housing.stl
48.0 x 54.0 x 20.8

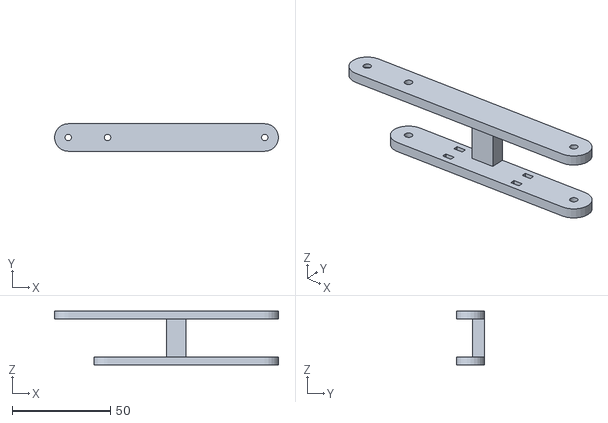
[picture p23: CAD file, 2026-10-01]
web/public/models/forearm.stl
114.0 x 14.0 x 27.3

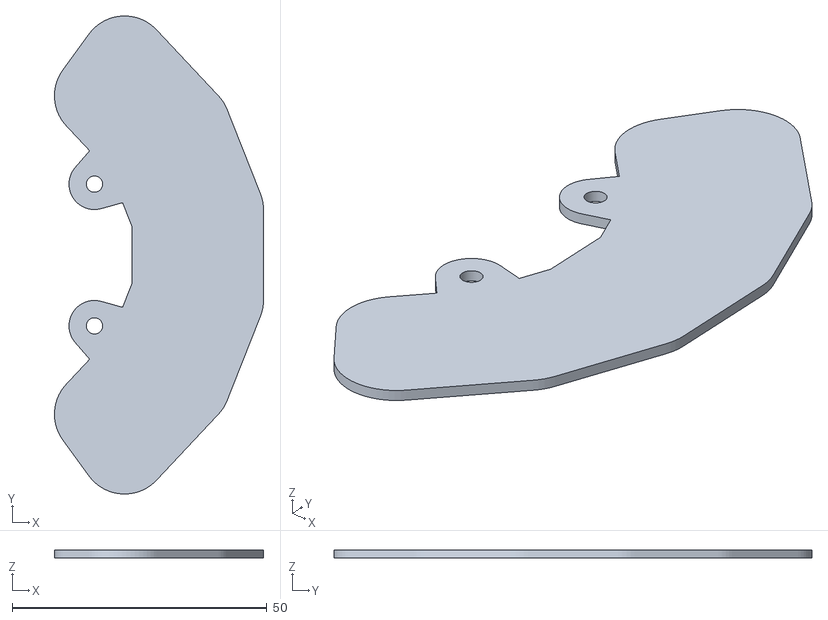
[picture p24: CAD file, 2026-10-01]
cad/stl/07_crank_lid.stl
41.0 x 93.8 x 1.60

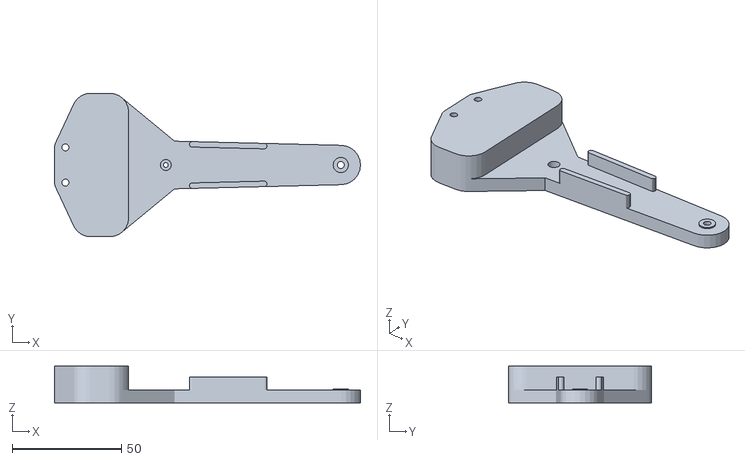
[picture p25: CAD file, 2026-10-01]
web/public/models/upper_arm.stl
139.9 x 65.6 x 16.9

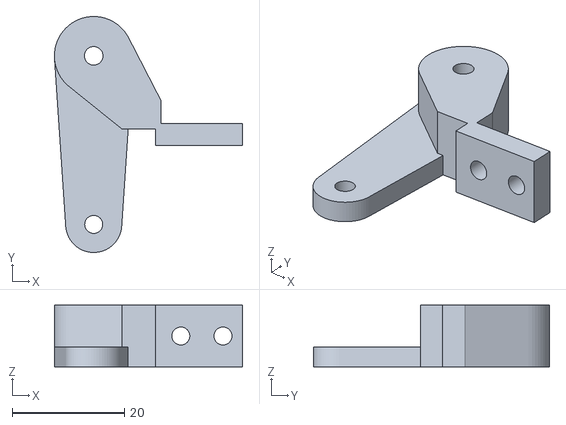
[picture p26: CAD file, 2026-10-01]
cad/stl/15_wrist_bracket.stl
33.5 x 42.0 x 11.0

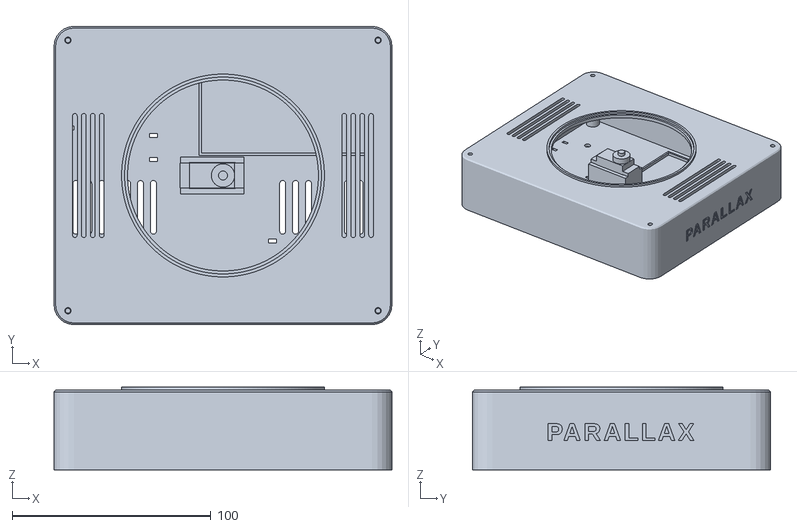
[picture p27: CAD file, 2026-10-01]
web/public/models/base.stl
170.0 x 150.0 x 41.5

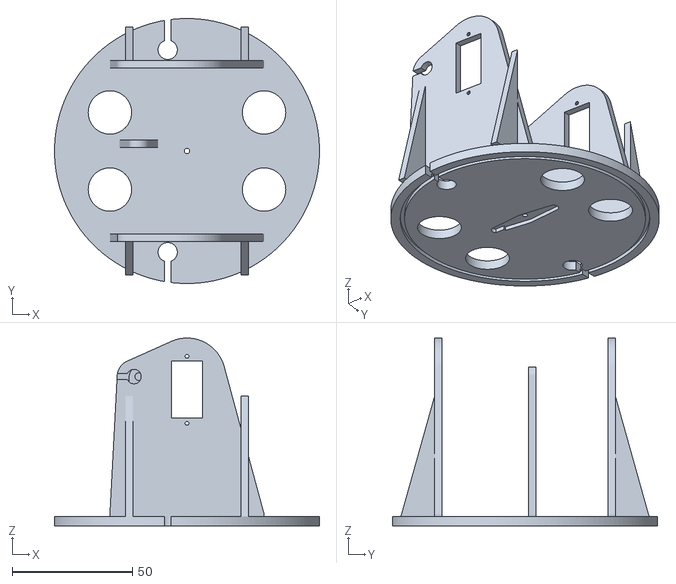
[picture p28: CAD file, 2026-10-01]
cad/stl/03_turret.stl
110.0 x 110.0 x 78.0

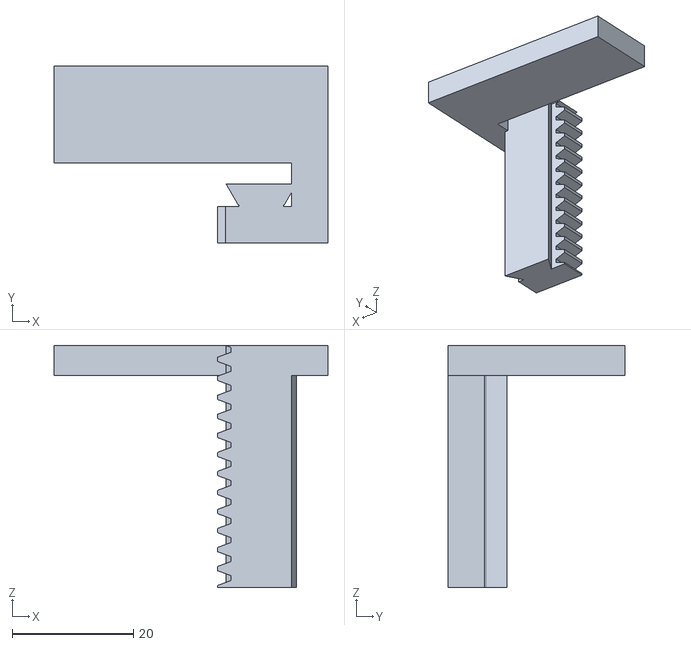
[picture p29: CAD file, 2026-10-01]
web/public/models/jaw_l.stl
45.2 x 29.2 x 40.0

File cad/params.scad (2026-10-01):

// Unica fonte delle quote. Le lunghezze dei link devono coincidere con calc/torque.py.
// Tolleranze: i default vanno bene per una stampante tarata in PLA (Kobra S1).
// Solo se qualcosa non calza: stampa cad/test/tolerance_coupon.scad e riporta qui i valori.
$fn = 64;

// ---- tolleranze (mm) ----
clr_hole  = 0.2;   // gioco diametrale fori passanti (M3 -> 3.2)
clr_pivot = 0.3;   // gioco diametrale fori su cui qualcosa RUOTA
clr_pocket = 0.2;  // gioco per lato in sedi (servo, squadretta, dado, piombi)
clr_slide = 0.3;   // riduzione per lato del pezzo maschio nelle guide a scorrimento
clr_servo = 0.3;   // gioco per lato nelle finestre degli SG90: i cloni variano 22.5-23.2 x 12.0-12.6 (sim/structural)
snap_hook = 0.8;   // sporgenza dente a scatto: con 0.4 la scheda usciva nel 47% dei cloni (sim/structural)

// ---- geometria braccio ----
L1 = 80;   // spalla -> gomito
L2 = 80;   // gomito -> perno polso
L3 = 42;   // perno polso -> centro dita (= xp in wrist.scad)

// ---- SG90 (misura il tuo e correggi) ----
sg_body   = [22.8, 12.4, 22.7];  // x lungo, y largo, z alto (senza linguette/perno)
sg_tab_len = 32.3;               // ingombro linguette
sg_tab_t  = 2.5;
sg_tab_z  = 15.9;                // quota della faccia inferiore delle linguette
sg_screw_pitch = 27.8;
sg_screw_d = 2.0;
sg_shaft_x = 5.9;                // asse albero dal bordo del corpo lato albero
sg_boss_d = 11.8;
sg_boss_h = 4.0;

// ---- squadretta doppia SG90: valori tipici con un filo di margine (una tasca un po' larga non conta: la tiene la vite) ----
horn_len  = 33.5;  // punta-punta (33.5: entra anche con squadrette lunghe, sim/structural)
horn_hub_d = 7.2;
horn_tip_d = 4.0;
horn_t    = 1.5;   // spessore del piatto
horn_screw_d = 2.0; // vite centrale

// ---- viteria ----
m3_d = 3.0;
m3_nut_af = 5.5;     // chiave del dado
m3_nylock_h = 4.0;
m3_head_d = 5.5;

// ---- contrappeso: piombi da pesca a oliva 20 g (misurati col calibro) ----
lead_l = 22.18;
lead_d = 13.70;
lead_pocket = [lead_l + 0.6, lead_d + 2 * clr_pocket];  // sede a stadio: lunghezza, larghezza
lead_depth = lead_d + 0.4;
lead_wall = 1.6;
lid_t = 1.6;                 // coperchio sedi, 2 viti M3x16
cw_t = lead_depth + 1.2;     // spessore del blocco contrappeso (fondo 1.2)
cw_shoulder_r = 30;          // = R_CW_SHOULDER in calc/torque.py
cw_elbow_r = 43;             // raggio dell'arco dei 4 piombi sulla manovella

// ---- SG90: quota della faccia ESTERNA della squadretta dal fondo del servo (tipico SG90 con squadretta doppia) ----
sg_horn_face = 30.5;

// ---- torretta ----
sh_h = 62;        // asse spalla sopra il fondo del pavimento torretta (z=0 = faccia squadretta base)
cheek_t = 3;
turret_w = 69;    // luce interna tra le guance
floor_t = 4;
floor_r = 55;
base_lip = [49.5, 51.0];   // labbro della base che entra nella gola sotto la torretta (guida radiale)
base_hole_r = 48;          // apertura centrale della base: i cavi scendono dai fori della torretta
horn_gap = sg_horn_face - (sg_tab_z + sg_tab_t) - cheek_t;  // guancia interna -> faccia squadretta (9.1)

// ---- manovella gomito (parallelogramma) ----
crank_r = 20;          // perno biella = leva posteriore avambraccio
crank_t = 4;
crank_spacer = 3.3;     // mozzo: stacca la piastra dalla squadretta per far stare la coppa lato guancia
rod_t = 4;             // bielle motrice e livellamento 1 (spessore)
rod2_t = 3;            // biella livellamento 2
rod_w = 6;             // larghezza corpo bielle (occhi d8)
lev_r = 20;            // leva di livellamento: perno fisso G = asse spalla + (-lev_r, 0)

// ---- piani lungo Y (0 = mezzeria torretta, guancia sinistra = servo spalla) ----
y_wall = turret_w / 2;
y_arm = -y_wall + horn_gap;                          // faccia z=0 del braccio (lato servo)
y_crank_hub = y_wall - horn_gap;                     // faccia squadretta manovella
y_crank_in = y_crank_hub - crank_spacer - crank_t;   // faccia interna piastra manovella
y_lev = [-3.0, 1.0];        // biella di livellamento 1 (G -> triangolo)
y_post = [1.5, 4.5];        // montante fisso che porta G
y_rod = [9.0, 13.0];        // biella motrice
// al gomito (avambraccio a U: piastra L + piastra R unite da un ponte)
y_fore_l = [-18.8, -14.8];
y_rod2 = [-10.5, -7.5];     // biella di livellamento 2 (triangolo U -> staffa polso V)
y_link = [-7.0, -3.5];      // triangolo di livellamento al gomito (dadi P1/U incassati)
y_fore_r = [4.5, 8.5];      // piastra R con la leva B (dado B incassato sul lato -y)
y_bracket = [-7.0, 4.0];    // staffa polso tra le piastre; la sua leva V sta in y_link
// limiti di giunto derivati dai piani (verificati in assembly.scad)
lim_phi = [-70, 70];
lim_e = [35, 150];          // th2 - phi; 35 e non 20: sotto, il parallelogramma amplifica la cedevolezza (sim/structural)

// ---- quote globali per firmware/web (docs/03-protocollo.md) ----
base_h = 40;      // tavolo -> faccia inferiore torretta (= faccia squadretta del servo base)
tcp_dz = -24;     // quota del centro dita rispetto al perno polso (= tcp_z in wrist.scad)
lev2_r = 30;      // leva del secondo parallelogramma di livellamento (verso l'alto al gomito)

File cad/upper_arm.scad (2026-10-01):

// Braccio (spalla -> gomito). Si stampa in piano così com'è: faccia z=0 sul piatto, nessun supporto.
// Asse spalla nell'origine, gomito a +X. La faccia z=0 guarda il servo spalla (squadretta in tasca).
// La faccia z=t guarda l'interno della torretta: lì stanno avambraccio e contrappeso; la canalina è sul lato servo.
//
// Montaggio:
//  1. avvita la squadretta doppia nella tasca con le sue viti autofilettanti (fori pilota da fare con la vite);
//  2. innesta sull'albero SG90 in posizione centrale (90°) con il braccio a 45°, poi vite centrale dal lato z=t;
//  3. gomito: vite M3x25 dalla faccia z=0, poi avambraccio, poi dado autobloccante, serrato "a scorrimento";
//  4. 4 piombi da 20 g nelle sedi di coda, coperchio (part="lid"), 2 viti M3x16 con dado nella sede lato z=0.
include <params.scad>
use <lib/parts.scad>

part = "arm";  // arm | lid | all

t = 6;                     // spessore del braccio
hub_r = 11;                // mozzo spalla: contiene la squadretta con margine
elbow_r = 9;               // braccio largo 22 -> 18: più rigido fuori piano e a torsione (sim/structural)
lead_y = (lead_pocket[1] + 2) / 2;               // sedi affiancate, setto di 2 mm
// 4 sedi in fila trasversale: baricentro sempre a cw_shoulder_r, la coda non si allunga verso il pavimento
leads = [for (k = [-3, -1, 1, 3]) [-cw_shoulder_r, k * lead_y]];
screws = [[-cw_shoulder_r - lead_pocket[0] / 2 - 4.5, lead_y], [-cw_shoulder_r - lead_pocket[0] / 2 - 4.5, -lead_y]];
rib = [2.5, 6, 12, L1 - 35];  // nervature sulla faccia interna: larghezza, altezza, da x, a x (lontane dal gomito:
                             // l'avambraccio ripiegato, th2-phi = 150, passa sopra gli ultimi ~35 mm: verificato con check_grid.sh)
chan_w = 5;                // canalina cavi (pinza SG90 + ESP32-CAM)
chan_d = 3;

module tail_outline(o) hull() {
    for (p = leads) translate(p) lead_outline(o);
    for (p = screws) translate(p) circle(r = 5);
}

module upper_arm() {
    difference() {
        union() {
            linear_extrude(t) {
                hull() {
                    circle(r = hub_r);
                    translate([L1, 0]) circle(r = elbow_r);
                }
                hull() {
                    circle(r = hub_r);
                    tail_outline(lead_wall);
                }
            }
            linear_extrude(cw_t) tail_outline(lead_wall);
            translate([L1, 0, t]) cylinder(d = 7, h = 0.5);  // rondella di scorrimento verso l'avambraccio
            // nervature lungo i bordi, sulla faccia interna (in stampa è quella in alto)
            for (s = [-1, 1]) hull() for (x = [rib[2], rib[3]]) {
                hw = hub_r + (elbow_r - hub_r) * x / L1;   // semilarghezza del braccio in x
                translate([x, s * (hw - rib[0] / 2), t - 0.01]) cylinder(d = rib[0], h = rib[1], $fn = 16);
            }
        }

        // spalla: squadretta lungo X, vite centrale con lamatura per la testa lato z=t
        horn_pocket(clr_pocket, t + 1);
        translate([0, 0, horn_t + 0.2 + 1.5]) cylinder(d = 5, h = t);

        // gomito: foro M3 (il perno è la vite; l'avambraccio ruota con clr_pivot)
        translate([L1, 0, -1]) cylinder(d = m3_d + clr_hole, h = t + 3);

        // contrappeso: sedi piombi aperte verso z=t, viti del coperchio con dado in sede sul lato z=0
        for (p = leads) translate([p.x, p.y, cw_t - lead_depth]) linear_extrude(lead_depth + 1) lead_outline();
        for (p = screws) translate([p.x, p.y, 0]) {
            translate([0, 0, -1]) cylinder(d = m3_d + clr_hole, h = cw_t + 2);
            translate([0, 0, -0.01]) rotate(30) hex_pocket(h = 2.6);
        }

        // canalina cavi sulla faccia z=0 (lato servo): al gomito il cavo fa l'ansa all'esterno, lontano dall'avambraccio.
        // 3 ponticelli sul piatto trattengono i fili (fessura di 2.2 mm: il piattino si infila di taglio)
        difference() {
            translate([18, -chan_w / 2, -1]) cube([L1 - 18 - elbow_r - 2, chan_w, chan_d + 1]);
            for (x = [30, 46, 62]) translate([x, 0, -1]) difference() {
                translate([0, -chan_w / 2, 0]) cube([3, chan_w, 1.8]);
                translate([-1, -1.1, -1]) cube([5, 2.2, 4]);
            }
        }
    }
}

module arm_lid() difference() {
    linear_extrude(lid_t) tail_outline(lead_wall);
    for (p = screws) translate([p.x, p.y, -1]) cylinder(d = m3_d + clr_hole, h = lid_t + 2);
}

if (part == "arm" || part == "all") upper_arm();
if (part == "lid") arm_lid();
if (part == "all") translate([0, 45, 0]) arm_lid();

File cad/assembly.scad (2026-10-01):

// Assieme completo nel frame torretta (yaw = 0) per anteprima e verifica collisioni.
// Pose: th2 = angolo assoluto braccio, phi = angolo assoluto avambraccio (0 = orizzontale avanti), g = apertura pinza.
// Limiti: 20 <= th2 <= 160, -70 <= phi <= 70, 35 <= th2 - phi <= 150 (docs/03-protocollo.md).
// Verifica: openscad -D check=1 -D th2=.. -D phi=.. -D g=.. -o out.stl assembly.scad -> deve risultare VUOTO.
// Controlla ogni coppia di parti più la ferramenta (teste viti, dadi autobloccanti, distanziali).
include <params.scad>
use <turret.scad>
use <upper_arm.scad>
use <crank.scad>
use <linkage.scad>
use <wrist.scad>
use <base.scad>
use <twin.scad>
use <cables.scad>

th2 = 60;
phi = 0;
g = 30;
check = 0;
pi = 0;
pj = 1;
show_cables = false;
psi = phi + 180;  // la manovella punta opposta all'avambraccio

function u(a) = [cos(a), 0, sin(a)];
function Y(p, y) = [p.x, y, p.z];
O = [0, 0, sh_h];
E = O + L1 * u(th2);
W = E + L2 * u(phi);
A = O + crank_r * u(psi);
B = E + crank_r * u(psi);
G = O + lev_r * u(180);
P1 = E + lev_r * u(180);
U = E + lev2_r * u(90);
V = W + lev2_r * u(90);

// frame del contratto: P(p, a) = T(p) Ry(-a) Rx(-90)
module P(p, a) translate(p) rotate([0, -a, 0]) rotate([-90, 0, 0]) children();

module arm() P(Y(O, y_arm), th2) {
    upper_arm();
    translate([0, 0, cw_t]) arm_lid();
    for (x = [-cw_shoulder_r - lead_pocket[0] / 2 - 4.5], y = [-1, 1] * (lead_pocket[1] + 2) / 2)
        translate([x, y, cw_t + lid_t]) cylinder(d = m3_head_d, h = 3);  // teste viti coperchio
}

module part(i) {
    if (i == 0) turret();
    if (i == 1) arm();
    if (i == 2) P(Y(O, y_crank_in), psi) crank_assembly();
    if (i == 3) P(Y(A, y_rod[0]), th2) drive_rod();
    if (i == 4) P(Y(G, y_lev[0]), th2) lev_rod();
    if (i == 5) P(Y(E, y_fore_l[0]), phi) forearm();
    if (i == 6) P(Y(E, y_link[0]), 0) lev_link();
    if (i == 7) P(Y(U, y_rod2[0]), phi) lev_rod2();
    if (i == 8) translate(W) wrist_assembly(g, lite = check > 0);
    if (i == 9) hardware();
}
N = 10;

// Ferramenta: cilindro lungo Y in p da y0 a y1.
module pin(p, y0, y1, d) translate([p.x, y0, p.z]) rotate([-90, 0, 0]) cylinder(d = d, h = y1 - y0);
module head(p, y, dir) pin(p, dir > 0 ? y + 0.1 : y - 3.1, dir > 0 ? y + 3.1 : y - 0.1, m3_head_d);
module nylock(p, y, dir) pin(p, dir > 0 ? y + 0.1 : y - 4.1, dir > 0 ? y + 4.1 : y - 0.1, 6.4);
module hardware() {
    head(E, y_arm, -1);             nylock(E, y_fore_r[1], 1);
    pin(E, y_fore_l[1] + 0.1, y_link[0] - 0.1, 6);  pin(E, y_link[1] + 0.1, y_fore_r[0] - 0.1, 5);
    head(W, y_fore_l[0], -1);       nylock(W, y_fore_r[1], 1);
    pin(W, y_fore_l[1] + 0.1, y_bracket[0] - 0.1, 6);
    head(A, y_crank_in + crank_t, 1);                       // dado incassato nella biella motrice
    head(B, y_rod[1], 1);                                   // dado incassato nella piastra R
    head(G, y_lev[0], -1);          nylock(G, y_post[1], 1);
    head(P1, y_lev[1], 1);                                  // dado incassato nel triangolo
    head(U, y_rod2[0], -1);                                 // dado incassato nel triangolo
    head(V, y_rod2[0], -1);         nylock(V, y_link[1], 1);
}

if (check == 0) {
    colors = ["SteelBlue", "Orange", "Gold", "Gray", "Gray", "Orange", "Silver", "Gray", "White", "Black"];
    for (i = [0:N - 1]) color(colors[i]) part(i);
    color("DimGray") translate([0, 0, -base_h]) { tray(); lid(); }   // base (solo anteprima)
    cheek_servo(-1); cheek_servo(1);
    translate(W) wrist_servo();
    if (show_cables) cables(th2, phi);
} else if (check == 2) {
    intersection() { part(pi); part(pj); }   // una coppia, per isolare una collisione
} else {
    for (i = [0:N - 2], j = [i + 1:N - 1]) intersection() { part(i); part(j); }
}

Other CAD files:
cad/stl/06_crank.stl
web/public/models/lev_link.stl
cad/stl/13_forearm.stl
web/public/models/jaw_r.stl
cad/base.scad
cad/cables.scad
cad/crank.scad
cad/linkage.scad
cad/stl/00_tolerance_coupon.stl
cad/stl/01_base_tray.stl
cad/stl/02_base_lid.stl
cad/stl/04_upper_arm.stl
cad/stl/05_upper_arm_lid.stl
cad/stl/08_crank_spacer.stl
cad/stl/10_lev_rod.stl
cad/stl/11_lev_rod2.stl
cad/stl/12_lev_link.stl
cad/stl/14_elbow_wrist_spacers.stl
cad/stl/19_gripper_jaw_x2.stl
cad/stl/20_esp32cam_cradle.stl
cad/stl/tolerance_coupon.stl
cad/stl/upper_arm.stl
cad/test/tolerance_coupon.scad
cad/turret.scad
cad/twin.scad
cad/wrist.scad
web/public/models/drive_rod.stl
web/public/models/lev_rod.stl
web/public/models/lev_rod2.stl

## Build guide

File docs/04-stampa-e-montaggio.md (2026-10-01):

# Stampa, ferramenta e montaggio

## 0. Tolleranze (facoltativo)

Le tolleranze di default in `cad/params.scad` vanno bene per una stampante tarata in PLA:
- ±0.2 mm sui fori e nelle sedi;
- 0.3 mm sulle guide a coda di rondine;
- sede della squadretta con un filo di margine: tanto la tiene la vite.

Gli STL in `cad/stl/` sono **pronti da stampare così come sono**.

Il provino `00_tolerance_coupon.stl` serve solo se qualcosa non calza. In quel caso:
1. riporta i valori in `params.scad`;
2. lancia `cad/export.sh` per rigenerare tutto (STL, twin, `rig.json`);
3. `python3 calc/torque.py` e `cad/assembly.scad` ricontrollano coppie e collisioni.

## 1. Stampa (Kobra S1, PLA)

Profilo: ugello 0.4, layer 0.2 (0.16 per pignone e ganasce), 3 perimetri, gyroid 20%, **nessun supporto**.
Tutti gli STL sono già orientati sul piatto.

| File | Qtà | Note |
|---|---|---|
| 01_base_tray | 1 | il pezzo più lungo (~4 h) |
| 02_base_lid | 1 | labbro di guida verso l'alto |
| 03_turret | 1 | guance verticali |
| 04_upper_arm + 05_upper_arm_lid | 1 + 1 | |
| 06_crank + 07_crank_lid + 08_crank_spacer | 1 + 1 + 1 | sedi dei piombi aperte sul piatto (ponti da 14 mm) |
| 09_drive_rod, 10_lev_rod, 11_lev_rod2, 12_lev_link | 1 ciascuno | |
| 13_forearm | 1 | stampato di fianco |
| 14_elbow_wrist_spacers | 1 set | 3 distanziali |
| 15_wrist_bracket | 1 | stampato di fianco |
| 16_gripper_housing | 1 | capovolto |
| 17_gripper_base_plate | 1 | code di rondine verso l'alto |
| 18_gripper_pinion | 1 | layer 0.16 |
| 19_gripper_jaw_x2 | **2** | stesso file due volte, layer 0.16 |
| 20_esp32cam_cradle | 1 | solo se monti la camera |

Totale **circa 230 g di PLA**.

Colori consigliati con la Combo:
- **grafite** per struttura (base, torretta, pinza);
- **arancio** per le parti in movimento (braccio, avambraccio, manovella, ganasce);
- **grigio chiaro** per bielle e triangolo.

La scritta PARALLAX sul fronte della base è incisa di 0.8 mm: con un cambio colore sugli ultimi layer viene in rilievo cromatico.

## 2. Ferramenta (tutta M3)

| Vite | Qtà | Dove |
|---|---|---|
| M3x6 | 1 | perno U (biella 2 → triangolo, dado incassato): più lunga entrerebbe nel piano della biella 1 |
| M3x8 | 8 | B (biella motrice → piastra R), P1 (biella 1 → triangolo), 2 culla camera, 4 coperchio base |
| M3x12 | 6 | G (montante), V (staffa polso), 2 piastra pinza, 2 staffa → piano pinza |
| M3x14 | 1 | A (manovella → distanziale → biella motrice, dado incassato) |
| M3x16 | 4 | coperchi dei piombi (2 braccio, 2 manovella) |
| M3x35 | 1 | perno polso W |
| M3x40 | 1 | perno gomito E: **acciaio 8.8 o 12.9** (brunita), non inox: è la vite più sollecitata a flessione |

- Dadi autobloccanti: 4, su E, W, G e V.
- Dadi normali: 10, su A, B, P1, U, 4 per i coperchi dei piombi e 2 per la staffa.
- **Frenafiletti medio** (una goccia) su A, B, P1, U: lì il dado è fisso nella sede e il pezzo ruota sulla vite, che altrimenti si svita.
- **Grasso** (PTFE o al litio) anche sulle code di rondine della pinza: la presa sale da 1.9 a 3.1 N per dito.
- **Serraggio:** dove ruota qualcosa (E, W, G, V) stringi l'autobloccante finché il giunto non ha gioco assiale **ma gira libero**.
  Prova pratica: senza le viti delle squadrette, braccio e avambraccio devono **cadere da soli** sotto il loro peso.
  Un dado troppo stretto (~10 N di precarico) basta, con un SG90 debole, a far perdere fino a 17° alla spalla in movimento (sim/dynamics).
  Una goccia di olio al silicone o grasso PTFE sui perni e sulla corona della base: il grasso sulla corona riduce anche il carico del servo base.

## 3. Montaggio

1. **Base.**
   - Nel vassoio: ESP32 a scatto nella culla (pin in basso) e breadboard nella cornice con il suo biadesivo.
   - WAGO fissati con fascette.
   - SG90 della base nella torre (cavo verso l'asola), poi il coperchio con 4 viti M3x8.
   - Cablaggio secondo [02-cablaggio.md](02-cablaggio.md).
2. **Torretta.** SG90 spalla (guancia −Y) e gomito (guancia +Y) montati **da fuori**, con le viti delle linguette.
3. **Taratura prima delle squadrette.**
   - Carica firmware e web app (sotto), apri la web app, premi **Abilita**.
   - I servo vanno alla posa `home` = [0°, 90°, 0°, 30 mm], cioè 1500 µs per base, spalla e gomito.
4. **Squadrette nella posa di riferimento.** Monta ogni pezzo con il servo in quella posa:
   - **torretta** con il braccio che punta avanti (+X);
   - **braccio verticale**;
   - **manovella orizzontale verso il retro**: così l'avambraccio sarà orizzontale;
   - **pinza semiaperta** (circa 30 mm).
5. **Piombi.**
   - **4 nella coda del braccio** (tutte le sedi).
   - **2 nelle sedi centrali della manovella**; le 4 laterali restano vuote.
     Con 4 il gomito risulterebbe bilanciato a vuoto e girerebbe libero nel gioco degli ingranaggi (sim/dynamics).
     Con 2 resta sempre caricato dallo stesso lato, e i tuoi 6 piombi bastano esattamente.
   - Chiudi i coperchi.
6. **Catena del gomito.** Monta avambraccio, triangolo e bielle secondo l'ordine delle viti di `cad/linkage.scad`, con distanziali e autobloccanti come in tabella.
   - Il triangolo deve restare **con la leva P1 orizzontale all'indietro e U in verticale**, in qualunque posa.
   - Se ruota insieme all'avambraccio, una biella è montata sul foro sbagliato.
7. **Polso e pinza.**
   - Servo capovolto sul piano, pignone sull'albero con la sua squadretta (vite dal basso), piastra inferiore con 2 viti.
   - Le ganasce si infilano di testa nelle code di rondine, A da +Y e B da −Y, finché ingranano. Con la pinza a 30 mm le dita devono essere simmetriche.
   - La staffa si avvita sul piano superiore.
8. **Rifinitura della taratura** nella scheda *Taratura* della web app:
   - porta ogni giunto su due angoli noti;
   - aggiorna `ref_us` e `k` (il segno di `k` è il verso);
   - salva con `cal_save`.

## 4. Firmware e web app

Dalla cartella del progetto:

```bash
cd web && npm install && npm run build          # scrive la web app compressa in firmware/data/
cd ../firmware
cp include/secrets.example.h include/secrets.h  # WiFi di casa e password tua per l'AP "BRACCIO" (consigliato)
~/.local/bin/pio run -e esp32dev -t upload      # firmware
~/.local/bin/pio run -e esp32dev -t uploadfs    # web app su LittleFS
```

Poi apri `http://braccio.local`. In alternativa usa l'AP `BRACCIO` (password `braccio-arm`) e vai su `http://192.168.4.1`.

Per sviluppare senza hardware: `cd web && npm run dev`. La web app parte in **simulazione** con lo stesso profilo di moto del firmware.

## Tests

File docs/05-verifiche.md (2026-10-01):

# Verifiche e simulazioni

Tutto si rigenera da zero con gli script indicati; i numeri qui sotto vengono dall'ultima esecuzione.
Sono simulazioni e modelli: **nessun pezzo è ancora stato stampato o provato su hardware**.

| Area | Come | Comando |
|---|---|---|
| Coppie statiche | lavoro virtuale, masse dagli STL | `python3 calc/torque.py` |
| Collisioni | intersezione di tutte le coppie di parti + viti/dadi/distanziali su una griglia di pose | `cad/check_grid.sh` |
| Dinamica | MuJoCo, catene chiuse, modello SG90 (anello P, banda morta, gioco, curva coppia-velocità), attriti, planner **vero** del firmware via ctypes | `sim/.venv/bin/python sim/dynamics/run_all.py` |
| Strutture e tolleranze | travi/lastre con anisotropia FDM, perni, ingranaggi, code di rondine, incastri, viti, creep, Monte Carlo 2000 robot | `python3 sim/structural/run_all.py` |
| Alimentazione | rete a nodi nel tempo (50 µs): caricatore, cavi, WAGO, condensatore, 4 SG90, ESP32 | `python3 sim/electrical/run_all.py` |
| Software | firmware ↔ twin su 6000 scenari, IK/FK su 1.5 M pose, fuzz (ASan/UBSan), protocollo end-to-end, UI in Chrome headless | `sim/software/run_all.sh` |

## Esiti

| Verifica | Esito | Numeri |
|---|---|---|
| Coppie, 50 g + ESP32-CAM | ✅ | SF ≥ 2.0 (calc), ≥ 1.9 nella pose peggiore della simulazione (spalla, braccio tutto indietro) |
| Collisioni | ✅ | 0 su tutta la griglia, incluso il cedimento della spalla a 17°; controllo negativo verificato |
| Moto pick&place a v=0.5 e v=1 | ✅ | nessun servo satura, duty max 0.72, overshoot < 0.05°, assestamento < 0.2 s |
| Precisione dei servo (banda morta + gioco) | ⚠️ | errore statico al TCP 1–6 mm a seconda del carico, errore d'arresto ~0.8–1° |
| Cedevolezza strutturale | ⚠️ | flessione elastica del TCP con 50 g + camera: **~5.5–6 mm** in home, **~13–14 mm** a sbraccio massimo (±30–50 %; le nervature coprono x 12–45, dove il momento è massimo) |
| Ripetibilità/accuratezza (Monte Carlo) | ⚠️ | p95 ~15 mm: è un braccio da pick&place di oggetti da 10–50 mm, non da precisione |
| E-stop (servo sganciati) | ✅ | il braccio scende lentamente, impatto ≤ 0.44 m/s con i piombi |
| Ingranaggi pinza | ✅ | 2.4 MPa allo stallo, ricoprimento 1.53, nessuna interferenza su tutta la rotazione |
| Incastri, viti, dadi | ✅ / ⚠️ | ESP32 trattenuto nel 100 % dei casi; pareti minime attorno ad alcuni dadi 0.55 mm |
| Accoppiamenti (cloni SG90, squadrette) | ⚠️ | squadretta 0 % da limare; SG90 nelle guance ~10 % da limare con una lima piatta |
| Alimentazione | ✅ con il cablaggio consigliato | cavo USB-C 3A corto, 2200 µF, enable sfalsato: servo ≥ 4.3 V. Con cavo da 1 m sottile: KO |
| Pinza in stallo | ❌ se chiusa a 0 mm su un oggetto | 0.7 A, >120 °C in 5 min → usa **Prendi** (larghezza − 1.5 mm) |
| Perno E / albero spalla | ⚠️ | vite M3 molto sollecitata a flessione: usa **acciaio 8.8 o 12.9**, non inox; l'albero dell'SG90 spalla porta ~20 N radiali |
| Software | ✅ | twin = firmware entro 0.004°, 0 crash nel fuzz, protocollo 17/17, UI 17/17 |

## Cosa è stato cambiato grazie alle verifiche

- **Dinamica:** il gomito con 4 piombi era perfettamente bilanciato e girava libero nel gioco → **2 piombi sulla manovella, 4 sulla coda del braccio**. Il calcolo statico era pessimista: la pinza livellata carica il gomito solo con leva L2.
- **Strutture:**
  - coda di rondine delle ganasce **staccata dal corpo** (fessura 0.3 mm) → collo aggiunto;
  - dadi della staffa del polso **sovrapposti** → interasse 7.5 mm;
  - braccio più largo con **nervature**, fazzoletti delle guance alti 50 mm;
  - vincolo **th2 − phi ≥ 35°** (era 20°): cedevolezza a sbraccio da ~54 a ~13 mm, sbraccio da 202 a 188 mm;
  - gioco servo e squadretta allargati, ganci ESP32 0.8 mm.
- **Elettrica:** servo agganciati **uno ogni 200 ms** all'enable (picco da ~2.7 a ~1.7 A); raccomandazioni su cavo, condensatore, interruttore e massa in [02-cablaggio.md](02-cablaggio.md).
- **Software:**
  - 4 bug del planner del firmware corretti;
  - il twin ora è il planner del firmware riga per riga;
  - E-STOP che scarta i comandi in coda;
  - `raw` che rispetta il vincolo;
  - taratura che non può allargare i limiti meccanici;
  - comando **Prendi** nella web app.

## Limiti onesti

- Un braccio SG90 + PLA + perni M3 ha **gioco e cedevolezza di qualche millimetro**: è normale per questa classe (MeArm, EEZYbot). Va bene per spostare oggetti leggeri; per la precisione servirebbero servo con cuscinetto (MG90S), perni d4 e un braccio a forcella.
- Il cedimento sotto carico è soprattutto elastico e ripetibile: una futura **compensazione di gravità** nel firmware (offset proporzionale al carico, coefficienti da misurare) può ridurre l'errore statico a ~1.5 mm.
- Le stime di rigidezza hanno ±30–50 % di incertezza (rigidezze di bordo fori, albero SG90, vincolo delle guance). La prova al banco consigliata: freccia del TCP in home con 50 g in pinza.
- Non tenere pose cariche per ore (creep del PLA e servo caldi): parcheggia appoggiato o premi E-STOP.

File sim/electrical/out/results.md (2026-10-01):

### dt

| passo | I picco [A] | V servo min [V] | 3V3 min [V] |
|---|---|---|---|
| 50 us | 2.435 | 3.688 | 2.945 |
| 20 us | 2.436 | 3.684 | 2.943 |

### S1

| caso | I picco caricatore [A] | V servo min 1ms (istant.) [V] | V WAGO min [V] | 3V3 min [V] | offset massa max/min [V] | livello alto visto dal servo min [V] | I jumper massa max [A] | trip | ESITO |
|---|---|---|---|---|---|---|---|---|---|
| consigliato, tutti insieme | 3.20 | 4.33 (4.29) | 4.52 | 3.03 | +0.16/-0.03 | 2.93 | 0.43 | 0 | OK |
| consigliato, sfalsato 200 ms | 1.83 | 4.52 (4.46) | 4.81 | 3.22 | +0.17/-0.03 | 3.13 | 0.43 | 0 | OK |
| migliore, tutti insieme | 3.14 | 4.27 (4.22) | 4.45 | 3.02 | +0.16/-0.03 | 2.92 | 0.42 | 0 | riserva |
| migliore, sfalsato 200 ms | 1.80 | 4.47 (4.39) | 4.76 | 3.19 | +0.17/-0.03 | 3.13 | 0.41 | 0 | OK |
| nominale, tutti insieme | 2.68 | 3.94 (3.91) | 4.14 | 2.97 | +0.19/-0.02 | 2.84 | 0.77 | 0 | KO |
| nominale, sfalsato 200 ms | 1.76 | 4.23 (4.14) | 4.54 | 3.08 | +0.20/-0.02 | 3.00 | 0.48 | 0 | riserva |
| peggiore, tutti insieme | 2.44 | 3.69 (3.68) | 3.91 | 2.94 | +0.24/-0.03 | 2.77 | 0.85 | 0 | KO |
| peggiore, sfalsato 200 ms | 1.63 | 4.06 (3.95) | 4.40 | 3.01 | +0.24/-0.03 | 2.90 | 0.54 | 0 | riserva |

### S1_stagger

| cablaggio | sfalsamento [ms] | I picco [A] | V servo min [V] | 3V3 min [V] | enable completo dopo [ms] |
|---|---|---|---|---|---|
| nominale | 0 | 2.68 | 3.94 | 2.97 | 300 |
| nominale | 100 | 2.06 | 4.10 | 3.06 | 600 |
| nominale | 150 | 1.98 | 4.27 | 3.07 | 750 |
| nominale | 200 | 1.76 | 4.23 | 3.08 | 900 |
| nominale | 250 | 1.90 | 4.24 | 3.09 | 1050 |
| nominale | 300 | 1.76 | 4.33 | 3.08 | 1200 |
| peggiore | 0 | 2.44 | 3.69 | 2.94 | 300 |
| peggiore | 100 | 1.84 | 3.90 | 3.01 | 600 |
| peggiore | 150 | 1.76 | 3.97 | 3.01 | 750 |
| peggiore | 200 | 1.63 | 4.06 | 3.01 | 900 |
| peggiore | 250 | 1.83 | 3.88 | 3.02 | 1050 |
| peggiore | 300 | 1.61 | 4.10 | 3.00 | 1200 |

### S1_hotplug

| cablaggio | C [uF] | regolatore | I spunto picco [A] | 3V3 min [V] | ESITO |
|---|---|---|---|---|---|
| nominale | 470 | condiviso | 8.1 | 1.74 | KO |
| nominale | 1000 | condiviso | 9.0 | 1.22 | KO |
| nominale | 2200 | condiviso | 9.4 | 0.64 | KO |
| peggiore | 1000 | condiviso | 7.1 | 1.48 | KO |
| nominale | 1000 | separato | 9.1 | 2.72 | riserva |

### S2

| caso | I picco caricatore [A] | V servo min 1ms (istant.) [V] | V WAGO min [V] | 3V3 min [V] | offset massa max/min [V] | livello alto visto dal servo min [V] | I jumper massa max [A] | trip | ESITO |
|---|---|---|---|---|---|---|---|---|---|
| consigliato | 2.77 | 4.46 (4.33) | 4.64 | 3.09 | +0.12/-0.03 | 2.98 | 0.40 | 0 | OK |
| nominale | 2.31 | 4.12 (4.01) | 4.31 | 3.05 | +0.16/-0.02 | 2.91 | 0.66 | 0 | riserva |
| nominale, v=0.5 | 2.24 | 4.12 (4.00) | 4.32 | 3.03 | +0.15/-0.02 | 2.90 | 0.62 | 0 | riserva |
| peggiore | 2.09 | 3.92 (3.80) | 4.14 | 3.05 | +0.20/-0.02 | 2.87 | 0.72 | 0 | KO |
| peggiore, 2A | 2.09 | 3.92 (3.80) | 4.14 | 3.05 | +0.20/-0.02 | 2.87 | 0.72 | 0 | KO |
| nominale, senza C | 2.66 | 4.01 (3.71) | 4.20 | 2.80 | +0.16/-0.02 | 2.68 | 0.73 | 0 | riserva |
| nominale, senza massa comune | 2.22 | 4.06 (3.96) | 4.24 | 3.07 | +0.44/-0.11 | 2.86 | 0.00 | 0 | riserva |
| peggiore, senza massa comune | 1.96 | 3.82 (3.69) | 4.03 | 3.01 | +0.59/-0.12 | 2.71 | 0.00 | 0 | KO |
| nominale, profili sim/dynamics/current_profiles.csv | 2.43 | 4.10 (4.09) | 4.33 | 3.00 | +0.17/-0.00 | 2.89 | 0.65 | 0 | riserva |
| peggiore, profili sim/dynamics/current_profiles.csv | 2.39 | 3.75 (3.74) | 4.04 | 2.93 | +0.22/-0.00 | 2.78 | 0.78 | 0 | KO |

### S2_corr

| caso | I media caricatore [A] | I rms per servo [A] | I picco per servo [A] |
|---|---|---|---|
| consigliato | 0.81 | 0.42 / 0.34 / 0.36 / 0.22 | 0.77 / 0.84 / 0.84 / 0.76 |
| nominale | 0.81 | 0.41 / 0.33 / 0.35 / 0.21 | 0.75 / 0.82 / 0.81 / 0.73 |
| nominale, v=0.5 | 0.79 | 0.41 / 0.32 / 0.37 / 0.19 | 0.75 / 0.82 / 0.79 / 0.74 |
| peggiore | 0.81 | 0.40 / 0.33 / 0.35 / 0.21 | 0.74 / 0.81 / 0.80 / 0.72 |
| peggiore, 2A | 0.81 | 0.40 / 0.33 / 0.35 / 0.21 | 0.74 / 0.81 / 0.80 / 0.72 |
| nominale, senza C | 0.81 | 0.41 / 0.33 / 0.35 / 0.21 | 0.75 / 0.80 / 0.80 / 0.72 |
| nominale, senza massa comune | 0.81 | 0.41 / 0.33 / 0.35 / 0.21 | 0.75 / 0.82 / 0.81 / 0.73 |
| peggiore, senza massa comune | 0.81 | 0.40 / 0.32 / 0.34 / 0.21 | 0.74 / 0.81 / 0.80 / 0.72 |

### S3

| caso | duty driver | I media [A] | P iniziale [W] | forza/dito [N] | T avvolg. 60 s [°C] | T avvolg. regime [°C] | t a 80 °C [s] | t a 120 °C [s] | ESITO |
|---|---|---|---|---|---|---|---|---|---|
| comando 0 mm (45° oltre il contatto) | 1.00 | 0.70 | 3.04 | 4.8 | 84 | 141 | 44 | 285 | KO |
| comando 3° oltre il contatto | 0.28 | 0.19 | 1.04 | 1.5 | 48 | 73 | mai | mai | riserva |
| comando 2° oltre il contatto | 0.14 | 0.09 | 0.55 | 0.7 | 37 | 52 | mai | mai | OK |

### S4

| caso | I picco caricatore [A] | V servo min 1ms (istant.) [V] | V WAGO min [V] | 3V3 min [V] | offset massa max/min [V] | livello alto visto dal servo min [V] | I jumper massa max [A] | trip | ESITO |
|---|---|---|---|---|---|---|---|---|---|
| 3A, nominale | 2.91 | 3.99 (3.98) | 4.19 | 3.11 | +0.16/-0.01 | 2.96 | 0.80 | 0 | KO |
| 3A, peggiore | 2.71 | 3.67 (3.67) | 3.90 | 3.03 | +0.21/-0.01 | 2.84 | 0.90 | 0 | KO |
| 3A, migliore | 3.20 | 4.38 (4.36) | 4.57 | 3.25 | +0.12/-0.01 | 3.14 | 0.43 | 0 | OK |
| 3A, consigliato | 3.26 | 4.46 (4.44) | 4.65 | 3.28 | +0.12/-0.02 | 3.18 | 0.29 | 0 | OK |
| 2A, nominale | 2.33 | 3.22 (3.21) | 3.38 | 2.20 | +0.15/-0.01 | 2.07 | 0.66 | 0 | KO |
| 2A, peggiore | 2.34 | 3.15 (3.13) | 3.34 | 2.34 | +0.20/-0.01 | 2.18 | 0.78 | 0 | KO |
| 3A, peggiore, regolatori separati | 2.40 | 3.69 (3.69) | 3.92 | 3.11 | +0.21/-0.01 | 2.92 | 0.88 | 0 | KO |

### S4_cavi

| caso | I per servo [A] | caduta jumper+contatti+cavetto servo, A/R [V] | P per jumper 26AWG [mW] | P per contatto [mW] | dT jumper [K] | I cavo B [A] | caduta cavo B A/R [V] | P cavo B [W] | dT cavo B [K] | I massa via ESP32 [A] |
|---|---|---|---|---|---|---|---|---|---|---|
| 3A, nominale | 0.64 | 0.20 | 11 | 8 | 1.1 | 2.58 | 0.90 | 1.78 | 8 | 0.77 |
| 3A, peggiore | 0.59 | 0.23 | 15 | 11 | 1.5 | 2.38 | 1.30 | 2.41 | 11 | 0.87 |
| 3A, migliore | 0.71 | 0.19 | 14 | 5 | 1.4 | 2.85 | 0.35 | 0.68 | 6 | 0.40 |
| 3A, consigliato | 0.73 | 0.19 | 14 | 5 | 1.4 | 2.91 | 0.24 | 0.36 | 4 | 0.27 |
| 2A, nominale | 0.52 | 0.16 | 7 | 6 | 0.8 | 2.10 | 0.73 | 1.18 | 5 | 0.62 |
| 2A, peggiore | 0.52 | 0.20 | 12 | 8 | 1.2 | 2.09 | 1.14 | 1.87 | 8 | 0.76 |
| 3A, peggiore, regolatori separati | 0.59 | 0.23 | 15 | 11 | 1.5 | 2.38 | 1.30 | 2.41 | 11 | 0.87 |

### S5

| caso | I picco caricatore [A] | V servo min 1ms (istant.) [V] | V WAGO min [V] | 3V3 min [V] | offset massa max/min [V] | livello alto visto dal servo min [V] | I jumper massa max [A] | trip | ESITO |
|---|---|---|---|---|---|---|---|---|---|
| 2A, nominale, enable tutti insieme | 2.36 | 3.59 (3.58) | 3.76 | 2.83 | +0.19/-0.02 | 2.70 | 0.64 | 0 | KO |
| 2A, peggiore, enable tutti insieme | 2.27 | 3.52 (3.52) | 3.73 | 2.88 | +0.23/-0.03 | 2.71 | 0.78 | 0 | KO |
| 2A, nominale, enable sfalsato 200 ms | 1.80 | 4.19 (4.09) | 4.50 | 3.02 | +0.19/-0.02 | 2.94 | 0.49 | 0 | riserva |
| 2A, peggiore, enable sfalsato 200 ms | 1.60 | 4.05 (3.93) | 4.38 | 2.96 | +0.24/-0.03 | 2.84 | 0.53 | 0 | riserva |

### S6

| C [uF] | V servo min 1ms [V] | V servo min istant. [V] | ripple WAGO pk-pk [V] | I picco caricatore [A] | 3V3 min [V] |
|---|---|---|---|---|---|
| 0 | 3.54 | 3.39 | 1.49 | 2.63 | 2.68 |
| 100 | 3.54 | 3.40 | 1.44 | 2.64 | 2.70 |
| 470 | 3.60 | 3.55 | 1.21 | 2.65 | 2.84 |
| 1000 | 3.69 | 3.68 | 1.04 | 2.44 | 2.94 |
| 2200 | 3.77 | 3.77 | 0.93 | 2.34 | 3.08 |
| 4700 | 3.84 | 3.84 | 0.86 | 2.22 | 3.16 |

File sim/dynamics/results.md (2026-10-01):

# Risultati simulazione dinamica (generato da run_all.py)

Massa mobile totale (0 g, 4+2 piombi): 303 g. Coppie statiche REACH 50 g: spalla 0.646, gomito 0.399 kg·cm.

## 1. Tenuta statica

Errore a regime (comando − albero) dopo 2 s, avvicinamento da +2° e da −2°. T = coppia gravitazionale per lavoro virtuale. Duty = uscita del driver (1 = saturo).

| posa | carico | T spalla kg·cm | T gomito kg·cm | err spalla ° | err gomito ° | duty sp/gom | err TCP mm | I sp+gom mA | oscill. ° |
|---|---|---|---|---|---|---|---|---|---|
| REACH th2=35 phi=0 | 0 g | +0.32 (SF 5.0) | -0.00 (SF 1170.3) | -1.16 … -1.05 | +0.10 … +0.72 | 0.18 / 0.07 | 1.5 | 182 | 0.01 |
| REACH th2=35 phi=0 | 30 g | +0.52 (SF 3.1) | +0.24 (SF 6.7) | -1.90 … -1.47 | -1.18 … -0.97 | 0.36 / 0.18 | 4.1 | 423 | 0.00 |
| REACH th2=35 phi=0 | 50 g | +0.65 (SF 2.5) | +0.40 (SF 4.0) | -2.00 … -1.93 | -1.71 … -1.37 | 0.39 / 0.31 | 5.0 | 539 | 0.00 |
| REACH th2=35 phi=0 | 30 g + CAM | +0.60 (SF 2.7) | +0.34 (SF 4.7) | -2.00 … -1.77 | -1.55 … -1.21 | 0.39 / 0.27 | 4.8 | 510 | 0.00 |
| REACH th2=35 phi=0 | 50 g + CAM | +0.73 (SF 2.2) | +0.50 (SF 3.2) | -2.22 … -2.00 | -1.95 … -1.66 | 0.44 / 0.37 | 5.3 | 583 | 0.00 |
| BACK th2=160 phi=10 | 0 g | -0.37 (SF 4.4) | -0.00 (SF 1133.8) | +1.18 … +1.25 | -0.77 … -0.15 | 0.20 / 0.08 | 2.6 | 210 | 0.01 |
| BACK th2=160 phi=10 | 50 g + CAM | -0.84 (SF 1.9) | +0.50 (SF 3.2) | +2.50 … +2.59 | -1.73 … -1.65 | 0.53 / 0.32 | 5.9 | 649 | 0.00 |
| HOME | 0 g | +0.00 (SF ∞) | -0.00 (SF 1170.3) | -0.56 … +0.51 | -0.46 … +0.42 | 0.03 / 0.00 | 1.0 | 41 | 0.02 |
| HOME | 50 g + CAM | +0.00 (SF ∞) | +0.50 (SF 3.2) | -0.28 … +0.57 | -1.88 … -1.40 | 0.03 / 0.36 | 2.8 | 307 | 0.03 |

Gioco dei perni (clr_pivot 0.3 mm diametrale → 0.15 mm radiale, 2 perni in serie per biella): rotazione libera dell'avambraccio = 0.3 mm / (crank_r·sin(th2−phi)), del polso = 0.3/(lev_r·sin th2) + 0.3/(lev2_r·cos phi). Sotto carico è un offset ripetibile, a carico nullo è gioco vero.

| th2−phi | gioco avambraccio | TCP mm (L2) |
|---|---|---|
| 35° | ±0.75° | ±1.05 |
| 45° | ±0.61° | ±0.85 |
| 90° | ±0.43° | ±0.60 |
| 150° | ±0.86° | ±1.20 |

## 2. Pick & place tra pose estreme (planner del firmware)

Sequenza: home->sbraccio [-90, 35, 0, 40], chiude [-90, 35, 0, 22], giro+indietro [90, 160, 10, 22], giù davanti [0, 60, -70, 22], apre [0, 60, -70, 40], ->home [0, 90, 0, 30]. Oggetto 25 mm, payload attaccato per tutta la sequenza (prudente), sosta 0.8 s.

### 0 g v=0.5  (durata 19.1 s, vincoli max 1.7 µm)

| moto | durata s | servo | err inseg. max ° | overshoot ° | assest. s (±0.5°) | err finale ° | duty max | % saturo | |T| max kg·cm | err TCP max mm |
|---|---|---|---|---|---|---|---|---|---|---|
| home->sbraccio | 2.46 | base | 2.52 | 0.01 | 0.14 | +0.90 | 0.52 | 0 | 0.63 | 7.6 |
|  |  | spalla | 1.25 | 0.00 | 0.00 | -0.84 | 0.20 | 0 | 0.46 |  |
|  |  | gomito | 0.97 | 0.03 | 0.00 | -0.76 | 0.13 | 0 | 0.28 |  |
| chiude | 1.06 | base | 0.88 | 0.00 | 0.00 | +0.80 | 0.11 | 0 | 0.04 | 3.6 |
|  |  | spalla | 0.84 | 0.00 | 0.00 | -0.84 | 0.10 | 0 | 0.32 |  |
|  |  | gomito | 0.76 | 0.00 | 0.00 | -0.71 | 0.08 | 0 | 0.00 |  |
| giro+indietro | 4.46 | base | 2.68 | 0.01 | 0.18 | -0.90 | 0.56 | 0 | 0.97 | 9.1 |
|  |  | spalla | 2.08 | 0.00 | 0.00 | +0.96 | 0.41 | 0 | 0.65 |  |
|  |  | gomito | 0.85 | 0.01 | 0.00 | -0.76 | 0.10 | 0 | 0.19 |  |
| giù davanti | 2.70 | base | 2.48 | 0.01 | 0.13 | +0.89 | 0.51 | 0 | 0.86 | 4.5 |
|  |  | spalla | 2.37 | 0.00 | 0.00 | -0.56 | 0.48 | 0 | 0.58 |  |
|  |  | gomito | 1.36 | 0.01 | 0.00 | +0.00 | 0.23 | 0 | 0.52 |  |
| apre | 1.06 | base | 0.87 | 0.00 | 0.00 | +0.79 | 0.11 | 0 | 0.04 | 1.8 |
|  |  | spalla | 0.56 | 0.00 | 0.00 | -0.56 | 0.03 | 0 | 0.20 |  |
|  |  | gomito | 0.00 | 0.00 | 0.00 | +0.01 | 0.00 | 0 | 0.00 |  |
| ->home | 2.02 | base | 0.79 | 0.00 | 0.00 | +0.79 | 0.09 | 0 | 0.00 | 3.0 |
|  |  | spalla | 1.43 | 0.02 | 0.00 | -0.79 | 0.25 | 0 | 0.26 |  |
|  |  | gomito | 1.51 | 0.00 | 0.00 | -0.79 | 0.27 | 0 | 0.23 |  |

### 0 g v=1.0  (durata 13.6 s, vincoli max 1.8 µm)

| moto | durata s | servo | err inseg. max ° | overshoot ° | assest. s (±0.5°) | err finale ° | duty max | % saturo | |T| max kg·cm | err TCP max mm |
|---|---|---|---|---|---|---|---|---|---|---|
| home->sbraccio | 1.46 | base | 3.20 | 0.01 | 0.03 | +0.87 | 0.69 | 0 | 0.72 | 9.5 |
|  |  | spalla | 1.51 | 0.00 | 0.00 | -0.84 | 0.27 | 0 | 0.68 |  |
|  |  | gomito | 1.03 | 0.03 | 0.00 | -0.79 | 0.14 | 0 | 0.32 |  |
| chiude | 0.74 | base | 0.86 | 0.00 | 0.00 | +0.80 | 0.10 | 0 | 0.03 | 3.6 |
|  |  | spalla | 0.84 | 0.00 | 0.00 | -0.84 | 0.10 | 0 | 0.32 |  |
|  |  | gomito | 0.79 | 0.00 | 0.00 | -0.74 | 0.08 | 0 | 0.00 |  |
| giro+indietro | 2.46 | base | 3.11 | 0.02 | 0.17 | -0.90 | 0.67 | 0 | 1.15 | 10.3 |
|  |  | spalla | 2.48 | 0.00 | 0.00 | +0.96 | 0.51 | 0 | 0.84 |  |
|  |  | gomito | 0.88 | 0.01 | 0.00 | -0.77 | 0.11 | 0 | 0.23 |  |
| giù davanti | 1.58 | base | 2.91 | 0.01 | 0.12 | +0.88 | 0.62 | 0 | 0.95 | 5.4 |
|  |  | spalla | 3.32 | 0.04 | 0.18 | -0.41 | 0.72 | 0 | 0.79 |  |
|  |  | gomito | 2.46 | 0.00 | 0.00 | +0.76 | 0.51 | 0 | 0.92 |  |
| apre | 0.74 | base | 0.87 | 0.00 | 0.00 | +0.79 | 0.11 | 0 | 0.03 | 2.3 |
|  |  | spalla | 0.56 | 0.00 | 0.00 | -0.56 | 0.03 | 0 | 0.20 |  |
|  |  | gomito | 0.77 | 0.00 | 0.00 | +0.77 | 0.08 | 0 | 0.02 |  |
| ->home | 1.24 | base | 0.79 | 0.00 | 0.00 | +0.79 | 0.09 | 0 | 0.00 | 3.5 |
|  |  | spalla | 1.56 | 0.03 | 0.00 | -0.75 | 0.28 | 0 | 0.30 |  |
|  |  | gomito | 2.05 | 0.00 | 0.00 | -0.79 | 0.41 | 0 | 0.34 |  |

### 50 g v=0.5  (durata 19.1 s, vincoli max 3.4 µm)

| moto | durata s | servo | err inseg. max ° | overshoot ° | assest. s (±0.5°) | err finale ° | duty max | % saturo | |T| max kg·cm | err TCP max mm |
|---|---|---|---|---|---|---|---|---|---|---|
| home->sbraccio | 2.46 | base | 2.70 | 0.02 | 0.14 | +1.09 | 0.56 | 0 | 0.69 | 8.2 |
|  |  | spalla | 1.55 | 0.00 | 0.00 | -1.60 | 0.29 | 0 | 0.66 |  |
|  |  | gomito | 1.41 | 0.00 | 0.00 | -1.37 | 0.24 | 0 | 0.46 |  |
| chiude | 1.06 | base | 1.07 | 0.00 | 0.00 | +0.82 | 0.15 | 0 | 0.12 | 5.3 |
|  |  | spalla | 1.61 | 0.00 | 0.00 | -1.61 | 0.29 | 0 | 0.66 |  |
|  |  | gomito | 1.37 | 0.00 | 0.00 | -1.37 | 0.23 | 0 | 0.40 |  |
| giro+indietro | 4.46 | base | 2.84 | 0.02 | 0.16 | -1.09 | 0.60 | 0 | 0.99 | 10.9 |
|  |  | spalla | 2.86 | 0.00 | 0.00 | +1.83 | 0.60 | 0 | 0.81 |  |
|  |  | gomito | 1.75 | 0.01 | 0.00 | -1.68 | 0.33 | 0 | 0.41 |  |
| giù davanti | 2.70 | base | 2.45 | 0.02 | 0.13 | +1.07 | 0.50 | 0 | 0.94 | 5.7 |
|  |  | spalla | 3.22 | 0.00 | 0.00 | -1.04 | 0.70 | 0 | 0.93 |  |
|  |  | gomito | 1.65 | 0.00 | 0.00 | +0.48 | 0.30 | 0 | 0.48 |  |
| apre | 1.06 | base | 1.05 | 0.00 | 0.00 | +0.80 | 0.15 | 0 | 0.11 | 2.8 |
|  |  | spalla | 1.04 | 0.00 | 0.00 | -1.04 | 0.15 | 0 | 0.41 |  |
|  |  | gomito | 0.48 | 0.00 | 0.00 | +0.48 | 0.01 | 0 | 0.14 |  |
| ->home | 2.02 | base | 0.80 | 0.00 | 0.00 | +0.79 | 0.09 | 0 | 0.01 | 4.0 |
|  |  | spalla | 1.96 | 0.02 | 0.00 | -0.80 | 0.38 | 0 | 0.48 |  |
|  |  | gomito | 2.46 | 0.00 | 0.00 | -1.71 | 0.51 | 0 | 0.59 |  |

### 50 g v=1.0  (durata 13.6 s, vincoli max 3.4 µm)

| moto | durata s | servo | err inseg. max ° | overshoot ° | assest. s (±0.5°) | err finale ° | duty max | % saturo | |T| max kg·cm | err TCP max mm |
|---|---|---|---|---|---|---|---|---|---|---|
| home->sbraccio | 1.46 | base | 3.24 | 0.02 | 0.08 | +1.05 | 0.70 | 0 | 0.80 | 9.5 |
|  |  | spalla | 1.64 | 0.00 | 0.00 | -1.60 | 0.29 | 0 | 0.66 |  |
|  |  | gomito | 1.42 | 0.00 | 0.00 | -1.37 | 0.24 | 0 | 0.48 |  |
| chiude | 0.74 | base | 1.03 | 0.00 | 0.00 | +0.82 | 0.14 | 0 | 0.10 | 5.2 |
|  |  | spalla | 1.61 | 0.00 | 0.00 | -1.61 | 0.29 | 0 | 0.66 |  |
|  |  | gomito | 1.37 | 0.00 | 0.00 | -1.37 | 0.23 | 0 | 0.40 |  |
| giro+indietro | 2.46 | base | 3.77 | 0.02 | 0.14 | -1.09 | 0.84 | 0 | 1.15 | 13.1 |
|  |  | spalla | 3.25 | 0.00 | 0.00 | +1.83 | 0.70 | 0 | 0.88 |  |
|  |  | gomito | 1.79 | 0.00 | 0.00 | -1.69 | 0.33 | 0 | 0.43 |  |
| giù davanti | 1.58 | base | 2.92 | 0.02 | 0.13 | +1.07 | 0.62 | 0 | 1.08 | 6.2 |
|  |  | spalla | 3.62 | 0.00 | 0.00 | -1.03 | 0.80 | 0 | 0.99 |  |
|  |  | gomito | 1.63 | 0.00 | 0.00 | +0.46 | 0.29 | 0 | 0.57 |  |
| apre | 0.74 | base | 1.05 | 0.00 | 0.00 | +0.81 | 0.15 | 0 | 0.12 | 2.8 |
|  |  | spalla | 1.04 | 0.00 | 0.00 | -1.04 | 0.15 | 0 | 0.41 |  |
|  |  | gomito | 0.46 | 0.00 | 0.00 | +0.46 | 0.00 | 0 | 0.14 |  |
| ->home | 1.24 | base | 0.81 | 0.00 | 0.00 | +0.79 | 0.09 | 0 | 0.01 | 4.6 |
|  |  | spalla | 2.09 | 0.04 | 0.00 | -0.80 | 0.41 | 0 | 0.50 |  |
|  |  | gomito | 2.96 | 0.00 | 0.00 | -1.71 | 0.63 | 0 | 0.66 |  |

### 30 g + CAM v=0.5  (durata 19.1 s, vincoli max 3.1 µm)

| moto | durata s | servo | err inseg. max ° | overshoot ° | assest. s (±0.5°) | err finale ° | duty max | % saturo | |T| max kg·cm | err TCP max mm |
|---|---|---|---|---|---|---|---|---|---|---|
| home->sbraccio | 2.46 | base | 2.68 | 0.02 | 0.16 | +1.09 | 0.56 | 0 | 0.69 | 8.0 |
|  |  | spalla | 1.45 | 0.00 | 0.00 | -1.50 | 0.26 | 0 | 0.61 |  |
|  |  | gomito | 1.18 | 0.00 | 0.00 | -1.13 | 0.18 | 0 | 0.40 |  |
| chiude | 1.06 | base | 1.07 | 0.00 | 0.00 | +0.81 | 0.15 | 0 | 0.12 | 5.0 |
|  |  | spalla | 1.50 | 0.00 | 0.00 | -1.50 | 0.26 | 0 | 0.61 |  |
|  |  | gomito | 1.13 | 0.00 | 0.00 | -1.13 | 0.17 | 0 | 0.34 |  |
| giro+indietro | 4.46 | base | 2.81 | 0.02 | 0.17 | -1.08 | 0.59 | 0 | 0.99 | 10.6 |
|  |  | spalla | 2.76 | 0.00 | 0.00 | +1.71 | 0.58 | 0 | 0.76 |  |
|  |  | gomito | 1.62 | 0.01 | 0.00 | -1.55 | 0.29 | 0 | 0.36 |  |
| giù davanti | 2.70 | base | 2.45 | 0.02 | 0.13 | +1.06 | 0.50 | 0 | 0.94 | 5.4 |
|  |  | spalla | 3.09 | 0.00 | 0.00 | -0.97 | 0.67 | 0 | 0.88 |  |
|  |  | gomito | 1.52 | 0.00 | 0.00 | +0.51 | 0.27 | 0 | 0.43 |  |
| apre | 1.06 | base | 1.04 | 0.00 | 0.00 | +0.80 | 0.15 | 0 | 0.11 | 2.7 |
|  |  | spalla | 0.97 | 0.00 | 0.00 | -0.97 | 0.13 | 0 | 0.38 |  |
|  |  | gomito | 0.51 | 0.00 | 0.00 | +0.51 | 0.01 | 0 | 0.12 |  |
| ->home | 2.02 | base | 0.80 | 0.00 | 0.00 | +0.79 | 0.09 | 0 | 0.01 | 3.9 |
|  |  | spalla | 1.90 | 0.02 | 0.00 | -0.80 | 0.36 | 0 | 0.45 |  |
|  |  | gomito | 2.33 | 0.00 | 0.00 | -1.58 | 0.47 | 0 | 0.54 |  |

### 30 g + CAM v=1.0  (durata 13.6 s, vincoli max 3.2 µm)

| moto | durata s | servo | err inseg. max ° | overshoot ° | assest. s (±0.5°) | err finale ° | duty max | % saturo | |T| max kg·cm | err TCP max mm |
|---|---|---|---|---|---|---|---|---|---|---|
| home->sbraccio | 1.46 | base | 3.21 | 0.02 | 0.12 | +1.06 | 0.69 | 0 | 0.79 | 9.5 |
|  |  | spalla | 1.56 | 0.00 | 0.00 | -1.50 | 0.28 | 0 | 0.65 |  |
|  |  | gomito | 1.19 | 0.00 | 0.00 | -1.13 | 0.18 | 0 | 0.43 |  |
| chiude | 0.74 | base | 1.04 | 0.00 | 0.00 | +0.82 | 0.15 | 0 | 0.11 | 4.9 |
|  |  | spalla | 1.50 | 0.00 | 0.00 | -1.50 | 0.26 | 0 | 0.61 |  |
|  |  | gomito | 1.13 | 0.00 | 0.00 | -1.13 | 0.17 | 0 | 0.34 |  |
| giro+indietro | 2.46 | base | 3.74 | 0.02 | 0.15 | -1.08 | 0.83 | 0 | 1.15 | 12.9 |
|  |  | spalla | 3.15 | 0.00 | 0.00 | +1.71 | 0.68 | 0 | 0.83 |  |
|  |  | gomito | 1.64 | 0.01 | 0.00 | -1.56 | 0.30 | 0 | 0.37 |  |
| giù davanti | 1.58 | base | 2.92 | 0.02 | 0.15 | +1.07 | 0.62 | 0 | 1.08 | 5.9 |
|  |  | spalla | 3.51 | 0.00 | 0.00 | -0.97 | 0.77 | 0 | 0.94 |  |
|  |  | gomito | 1.51 | 0.00 | 0.00 | +0.52 | 0.26 | 0 | 0.49 |  |
| apre | 0.74 | base | 1.05 | 0.00 | 0.00 | +0.81 | 0.15 | 0 | 0.11 | 2.8 |
|  |  | spalla | 0.97 | 0.00 | 0.00 | -0.97 | 0.13 | 0 | 0.38 |  |
|  |  | gomito | 0.52 | 0.00 | 0.00 | +0.52 | 0.02 | 0 | 0.12 |  |
| ->home | 1.24 | base | 0.81 | 0.00 | 0.00 | +0.79 | 0.09 | 0 | 0.01 | 4.4 |
|  |  | spalla | 2.03 | 0.05 | 0.00 | -0.80 | 0.39 | 0 | 0.47 |  |
|  |  | gomito | 2.83 | 0.00 | 0.00 | -1.59 | 0.60 | 0 | 0.62 |  |

### 2b. What-if sui limiti del planner (v=1.0, copia di config.h solo in build/)

| SG90 | limiti planner | tempo in moto s | err inseg. max b/sp/gom ° | duty max b/sp/gom | % saturo b/sp/gom | overshoot b/sp/gom ° | I picco A |
|---|---|---|---|---|---|---|---|
| 1.6 kg·cm | firmware 90°/s, 180°/s² | 8.2 | 3.8 / 3.6 / 3.0 | 0.84 / 0.80 / 0.63 | 0 / 0 / 0 | 0.02 / 0.04 / 0.00 | 2.07 |
| 1.6 kg·cm | 135°/s, 540°/s² | 5.6 | 5.8 / 4.5 / 3.6 | 1.00 / 1.00 / 0.80 | 4 / 0 / 0 | 0.02 / 0.03 / 0.03 | 2.25 |
| 1.6 kg·cm | 180°/s, 720°/s² | 4.8 | 6.9 / 5.2 / 4.2 | 1.00 / 1.00 / 0.95 | 10 / 2 / 0 | 0.13 / 0.16 / 0.05 | 2.32 |
| 1.6 kg·cm | 90°/s, 720°/s² | 6.8 | 5.9 / 4.0 / 3.1 | 1.00 / 0.91 / 0.66 | 3 / 0 / 0 | 0.41 / 0.02 / 0.03 | 2.33 |
| 1.2 kg·cm | firmware 90°/s, 180°/s² | 8.2 | 4.3 / 4.4 / 3.5 | 0.96 / 0.98 / 0.76 | 0 / 0 / 0 | 0.03 / 0.01 / 0.00 | 2.30 |
| 1.2 kg·cm | 135°/s, 540°/s² | 5.6 | 8.4 / 5.5 / 4.2 | 1.00 / 1.00 / 0.94 | 18 / 5 / 0 | 0.08 / 0.04 / 0.05 | 2.48 |
| 1.2 kg·cm | 180°/s, 720°/s² | 4.8 | 11.8 / 6.9 / 4.9 | 1.00 / 1.00 / 1.00 | 26 / 10 / 1 | 0.37 / 0.08 / 0.09 | 2.49 |
| 1.2 kg·cm | 90°/s, 720°/s² | 6.8 | 7.5 / 5.0 / 3.7 | 1.00 / 1.00 / 0.83 | 10 / 2 / 0 | 0.78 / 0.02 / 0.06 | 2.49 |

## 3. E-stop: PWM sganciato (servo liberi, motore aperto)

Tenuta 0.3 s, poi sgancio. L'evento è il primo tra: TCP sul tavolo, spalla o gomito 5° oltre il limite di giunto, th2−phi 5° oltre il vincolo (urto tra parti). Simulazione fino a 3 s.

| posa | contrappesi | carico | evento | t evento s | Δth2 / Δphi ° | ω spalla / gomito °/s | v TCP m/s |
|---|---|---|---|---|---|---|---|
| REACH | 4+2 piombi | 0 g | fine corsa spalla | 0.30 | -19.0 / -1.0 | -118 / -4 | 0.17 |
| REACH | 4+2 piombi | 50 g | fine corsa spalla | 0.14 | -18.0 / -3.3 | -279 / -28 | 0.43 |
| REACH | senza piombi | 0 g | fine corsa spalla | 0.18 | -18.6 / -13.2 | -207 / -131 | 0.46 |
| REACH | senza piombi | 50 g | fine corsa spalla | 0.13 | -17.9 / -15.9 | -295 / -218 | 0.69 |
| alto avanti th2=60 phi=40 | 4+2 piombi | 0 g | vincolo th2-phi | 2.04 | -6.2 / -1.4 | -12 / -0 | 0.02 |
| alto avanti th2=60 phi=40 | 4+2 piombi | 50 g | vincolo th2-phi | 0.18 | -10.9 / -6.1 | -130 / -68 | 0.27 |
| alto avanti th2=60 phi=40 | senza piombi | 0 g | vincolo th2-phi | 0.47 | -42.3 / -37.3 | -248 / -181 | 0.59 |
| alto avanti th2=60 phi=40 | senza piombi | 50 g | fine corsa spalla | 0.26 | -43.6 / -43.9 | -425 / -318 | 1.02 |
| HOME | 4+2 piombi | 0 g | nessuno | > 3 | +0.0 / +0.0 | +0 / +0 | 0.00 |
| HOME | 4+2 piombi | 50 g | vincolo th2-phi | 0.60 | -0.7 / -64.6 | +0 / -49 | 0.07 |
| HOME | senza piombi | 0 g | nessuno | > 3 | -0.7 / -50.4 | +0 / -2 | 0.00 |
| HOME | senza piombi | 50 g | fine corsa gomito | 0.25 | -18.7 / -73.1 | -257 / -485 | 0.43 |
| BACK | 4+2 piombi | 0 g | fine corsa spalla | 0.09 | +3.8 / +0.3 | +68 / -0 | 0.10 |
| BACK | 4+2 piombi | 50 g | vincolo th2-phi | 0.03 | +1.2 / +0.1 | +74 / -6 | 0.11 |
| BACK | senza piombi | 0 g | vincolo th2-phi | 0.05 | +2.1 / -0.2 | +82 / -6 | 0.12 |
| BACK | senza piombi | 50 g | vincolo th2-phi | 0.01 | +0.0 / +0.0 | +14 / -1 | 0.02 |
| basso avanti th2=40 phi=-50 | 4+2 piombi | 0 g | fine corsa spalla | 0.39 | -24.1 / -1.5 | -123 / +0 | 0.17 |
| basso avanti th2=40 phi=-50 | 4+2 piombi | 50 g | fine corsa spalla | 0.15 | -23.2 / -3.5 | -314 / -8 | 0.44 |
| basso avanti th2=40 phi=-50 | senza piombi | 0 g | fine corsa spalla | 0.21 | -23.6 / -5.9 | -233 / -28 | 0.34 |
| basso avanti th2=40 phi=-50 | senza piombi | 50 g | fine corsa spalla | 0.13 | -22.8 / -11.0 | -364 / -107 | 0.56 |

## 4. Sensibilità (REACH statico e sequenza a v=1.0)

| carico | variante | T statica sp/gom kg·cm | SF min | err statico sp/gom ° | duty statico sp/gom | err inseg. max b/sp/gom ° | % saturo b/sp/gom | overshoot b/sp/gom ° | I picco tot A |
|---|---|---|---|---|---|---|---|---|---|
| 50 g | nominale | +0.65 / +0.40 | 2.5 | 2.00 / 1.71 | 0.39 / 0.31 | 3.8 / 3.6 / 3.0 | 0 / 0 / 0 | 0.02 / 0.04 / 0.00 | 2.07 |
| 50 g | SG90 1.2 kg·cm | +0.65 / +0.40 | 1.9 | 2.18 / 2.00 | 0.43 / 0.39 | 4.3 / 4.4 / 3.5 | 0 / 0 / 0 | 0.03 / 0.01 / 0.00 | 2.30 |
| 50 g | attrito alto | +0.65 / +0.40 | 2.5 | 2.26 / 1.93 | 0.45 / 0.37 | 4.1 / 4.6 / 4.2 | 0 / 1 / 0 | 0.02 / 0.11 / 0.08 | 2.31 |
| 50 g | manovella 2 piombi | +0.65 / +0.54 | 2.5 | 2.00 / 2.00 | 0.39 / 0.39 | 3.8 / 3.6 / 3.3 | 0 / 0 / 0 | 0.02 / 0.04 / 0.01 | 2.13 |
| 50 g | manovella 0 piombi | +0.65 / +0.71 | 2.2 | 2.00 / 2.13 | 0.39 / 0.42 | 3.7 / 3.6 / 3.7 | 0 / 0 / 0 | 0.02 / 0.05 / 0.01 | 2.20 |
| 50 g | braccio 0 piombi | +0.74 / +0.40 | 2.1 | 2.17 / 1.71 | 0.43 / 0.31 | 3.8 / 3.9 / 3.0 | 0 / 0 / 0 | 0.02 / 0.03 / 0.01 | 2.11 |
| 50 g | gioco 2° + banda 8 µs | +0.65 / +0.40 | 2.5 | 2.21 / 1.98 | 0.37 / 0.31 | 4.0 / 3.9 / 3.2 | 0 / 0 / 0 | 0.02 / 0.02 / 0.00 | 2.07 |
| 50 g | anello morbido (100% a 8°) | +0.65 / +0.40 | 2.5 | 3.58 / 2.31 | 0.39 / 0.23 | 6.5 / 6.2 / 4.6 | 0 / 0 / 0 | 0.04 / 0.01 / 0.00 | 1.62 |
| 50 g | corona ingrassata μ 0.1 | +0.65 / +0.40 | 2.5 | 2.00 / 1.71 | 0.39 / 0.31 | 3.1 / 3.6 / 3.0 | 0 / 0 / 0 | 0.10 / 0.04 / 0.01 | 1.91 |
| 50 g | 1.2 kg·cm + attrito alto | +0.65 / +0.40 | 1.9 | 2.45 / 2.00 | 0.50 / 0.39 | 4.6 / 8.6 / 5.1 | 0 / 26 / 6 | 0.03 / 0.05 / 0.08 | 2.47 |
| 30 g + CAM | nominale | +0.60 / +0.34 | 2.7 | 2.00 / 1.55 | 0.39 / 0.27 | 3.7 / 3.5 / 2.8 | 0 / 0 / 0 | 0.02 / 0.05 / 0.01 | 2.03 |
| 30 g + CAM | SG90 1.2 kg·cm | +0.60 / +0.34 | 2.0 | 2.06 / 1.92 | 0.40 / 0.37 | 4.2 / 4.2 / 3.3 | 0 / 0 / 0 | 0.03 / 0.01 / 0.00 | 2.24 |
| 30 g + CAM | attrito alto | +0.60 / +0.34 | 2.7 | 2.17 / 1.81 | 0.43 / 0.34 | 4.0 / 4.5 / 4.1 | 0 / 0 / 0 | 0.02 / 0.04 / 0.07 | 2.26 |
| 30 g + CAM | manovella 2 piombi | +0.60 / +0.49 | 2.7 | 2.00 / 1.92 | 0.39 / 0.36 | 3.7 / 3.5 / 3.2 | 0 / 0 / 0 | 0.02 / 0.05 / 0.01 | 2.08 |
| 30 g + CAM | manovella 0 piombi | +0.60 / +0.66 | 2.4 | 2.00 / 2.00 | 0.39 / 0.39 | 3.7 / 3.5 / 3.6 | 0 / 0 / 0 | 0.02 / 0.05 / 0.01 | 2.14 |
| 30 g + CAM | braccio 0 piombi | +0.70 / +0.34 | 2.3 | 2.00 / 1.55 | 0.39 / 0.27 | 3.7 / 3.7 / 2.8 | 0 / 0 / 0 | 0.02 / 0.04 / 0.01 | 2.06 |
| 30 g + CAM | gioco 2° + banda 8 µs | +0.60 / +0.34 | 2.7 | 2.05 / 1.85 | 0.33 / 0.28 | 4.0 / 3.8 / 3.1 | 0 / 0 / 0 | 0.02 / 0.03 / 0.01 | 2.03 |
| 30 g + CAM | anello morbido (100% a 8°) | +0.60 / +0.34 | 2.7 | 3.46 / 2.18 | 0.38 / 0.22 | 6.4 / 6.0 / 4.4 | 0 / 0 / 0 | 0.04 / 0.01 / 0.01 | 1.55 |
| 30 g + CAM | corona ingrassata μ 0.1 | +0.60 / +0.34 | 2.7 | 2.00 / 1.55 | 0.39 / 0.27 | 3.2 / 3.5 / 2.8 | 0 / 0 / 0 | 0.09 / 0.05 / 0.01 | 1.90 |
| 30 g + CAM | 1.2 kg·cm + attrito alto | +0.60 / +0.34 | 2.0 | 2.22 / 2.00 | 0.44 / 0.39 | 4.5 / 6.8 / 4.8 | 0 / 19 / 3 | 0.03 / 0.04 / 0.07 | 2.45 |

Fattore v del comando nei casi peggiori (50 g, sequenza completa):

| variante | v | duty max b/sp/gom | % saturo b/sp/gom | err inseg. max b/sp/gom ° |
|---|---|---|---|---|
| SG90 1.2 kg·cm | 0.5 | 0.79 / 0.87 / 0.62 | 0 / 0 / 0 | 3.6 / 3.9 / 2.9 |
| SG90 1.2 kg·cm | 0.7 | 0.85 / 0.92 / 0.67 | 0 / 0 / 0 | 3.8 / 4.1 / 3.1 |
| SG90 1.2 kg·cm | 1.0 | 0.96 / 0.98 / 0.76 | 0 / 0 / 0 | 4.3 / 4.4 / 3.5 |
| attrito alto | 0.5 | 0.68 / 0.89 / 0.79 | 0 / 0 / 0 | 3.2 / 4.0 / 3.6 |
| attrito alto | 0.7 | 0.75 / 0.95 / 0.85 | 0 / 0 / 0 | 3.4 / 4.2 / 3.8 |
| attrito alto | 1.0 | 0.91 / 1.00 / 0.94 | 0 / 1 / 0 | 4.1 / 4.6 / 4.2 |
| 1.2 kg·cm + attrito alto | 0.5 | 0.87 / 1.00 / 0.97 | 0 / 8 / 0 | 3.9 / 5.0 / 4.3 |
| 1.2 kg·cm + attrito alto | 0.7 | 0.95 / 1.00 / 1.00 | 0 / 17 / 1 | 4.2 / 6.0 / 4.6 |
| 1.2 kg·cm + attrito alto | 1.0 | 1.00 / 1.00 / 1.00 | 0 / 26 / 6 | 4.6 / 8.6 / 5.1 |

## 5. Corrente

Sequenza 50 g, v=1.0, nominale (`current_profiles.csv`, 1 kHz). I = I_idle 10 mA + 0.74 A × |coppia elettromagnetica| / stallo.

| servo | picco A | media A | RMS A |
|---|---|---|---|
| base | 0.58 | 0.163 | 0.191 |
| spalla | 0.55 | 0.174 | 0.203 |
| gomito | 0.44 | 0.158 | 0.183 |
| pinza | 0.75 | 0.420 | 0.531 |
| totale | 2.08 | 0.915 | 1.016 |

Presa di un pezzo da 25 mm: comando = larghezza − schiacciamento. Forza richiesta 1.6 N/dito (50 g, μ 0.3, SF 2).

| comando g | schiacciamento mm | forza/dito N | I a regime A | presa sicura |
|---|---|---|---|---|
| 24.5 mm | 0.5 | 0.5 | 0.08 | no |
| 24.0 mm | 1.0 | 1.7 | 0.23 | sì |
| 23.5 mm | 1.5 | 2.5 | 0.38 | sì |
| 23.0 mm | 2.0 | 3.5 | 0.53 | sì |
| 22.0 mm | 3.0 | 5.5 | 0.75 | sì |
| 20.0 mm | 5.0 | 5.5 | 0.75 | sì |
| 0.0 mm (chiudi tutto) | 25.0 | 5.5 | 0.75 | sì |

Enable con il braccio a 30°/40°/40° da home (base/spalla/gomito): velocità di picco 394 / 414 / 529 °/s, corrente totale di picco 2.55 A per 119 ms sopra 1.5 A.

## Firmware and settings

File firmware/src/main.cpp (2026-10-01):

// Firmware BRACCIO: 4 SG90 su LEDC, web app da LittleFS, comandi via WebSocket.
// Contratto con la web app: docs/03-protocollo.md.
// Le callback WS girano nel task di AsyncTCP: fanno solo parsing e accodano, il loop esegue.
#include <Arduino.h>
#include <WiFi.h>
#include <ESPmDNS.h>
#include <LittleFS.h>
#include <Preferences.h>
#include <ESPAsyncWebServer.h>
#include <ArduinoJson.h>
#if __has_include("secrets.h")
#include "secrets.h"  // prima di config.h: può ridefinire AP_PASS
#else
#define WIFI_SSID ""  // niente secrets.h: direttamente AP
#define WIFI_PASS ""
#endif
#include "config.h"
#include "motion.h"

AsyncWebServer server(80);
AsyncWebSocket ws("/ws");
Preferences prefs;

Cal cal[NJ];
float home[NJ];
Planner pl;
bool enabled = false;
bool known = false;  // posa nota: dopo il primo enable il planner parte dall'ultima posa comandata
int attachNext = NJ;  // prossimo servo da agganciare dopo l'enable (NJ: tutti agganciati o nessuno in attesa)
uint32_t tAttach = 0;
const char* netMode = "ap";

enum CmdType : uint8_t { C_MOVE, C_STOP, C_ENABLE, C_RAW, C_CAL_GET, C_CAL_SET, C_CAL_SAVE, C_HOME_SET };
struct Cmd {
    CmdType t;
    uint32_t client;
    float q[NJ], v;  // move: target e fattore; raw: v = us
    int j;           // raw: giunto
    Cal cal[NJ];
};
QueueHandle_t cmdq;
volatile bool estopReq = false;  // estop salta la coda: non deve mai perdersi

// ---- servo ----

static uint32_t duty(float us) { return lroundf(us * (1 << PWM_BITS) / PWM_PERIOD_US); }

static void writeServos() {
    for (int j = 0; j < NJ; j++) ledcWrite(j, duty(q_to_us(cal[j], pl.q[j])));
}

// Aggancio sfalsato: chiamata dal loop, un servo ogni ATTACH_STAGGER_MS per non sommare gli spunti
static void attachStep() {
    if (attachNext >= NJ || millis() - tAttach < ATTACH_STAGGER_MS) return;
    ledcAttachPin(PIN_SERVO[attachNext], attachNext);  // duty già scritto: il primo impulso è quello giusto
    attachNext++;
    tAttach = millis();
}

static void detachServos() {
    for (int j = 0; j < NJ; j++) {
        ledcDetachPin(PIN_SERVO[j]);
        pinMode(PIN_SERVO[j], OUTPUT);  // linea bassa: servo senza impulsi, senza coppia
        digitalWrite(PIN_SERVO[j], LOW);
    }
}

// ---- messaggi in uscita ----

static void send(uint32_t client, JsonDocument& doc) {  // client 0 = tutti
    String s;
    serializeJson(doc, s);
    if (client) ws.text(client, s);
    else ws.textAll(s);
}

static void sendErr(uint32_t client, const char* msg) {
    JsonDocument doc;
    doc["t"] = "err";
    doc["msg"] = msg;
    send(client, doc);
}

static float r2(float x) { return roundf(x * 100) / 100; }

static void sendCal(uint32_t client) {
    JsonDocument doc;
    doc["t"] = "cal";
    JsonArray a = doc["cal"].to<JsonArray>(), h = doc["home"].to<JsonArray>();
    for (int j = 0; j < NJ; j++) {
        JsonObject o = a.add<JsonObject>();
        o["ref_us"] = cal[j].ref_us;
        o["k"] = cal[j].k;
        o["q_ref"] = cal[j].q_ref;
        o["min"] = cal[j].min;
        o["max"] = cal[j].max;
        h.add(r2(home[j]));
    }
    send(client, doc);
}

static void sendState() {
    JsonDocument doc;
    doc["t"] = "state";
    JsonArray q = doc["q"].to<JsonArray>(), t = doc["target"].to<JsonArray>(), us = doc["us"].to<JsonArray>();
    for (int j = 0; j < NJ; j++) {
        q.add(r2(pl.q[j]));
        t.add(r2(pl.target[j]));
        us.add(r2(q_to_us(cal[j], pl.q[j])));
    }
    doc["moving"] = pl.moving();
    doc["enabled"] = enabled;
    send(0, doc);
}

// ---- comandi (eseguiti nel loop) ----

static void estop() {
    attachNext = NJ;
    detachServos();
    enabled = false;
    pl.halt();
}

static void handle(const Cmd& c) {
    char err[80];
    switch (c.t) {
    case C_MOVE:
        if (!enabled) return sendErr(c.client, "disabilitato: manda enable");
        if (attachNext < NJ) return sendErr(c.client, "enable in corso");
        if (!(c.v > 0 && c.v <= 1)) return sendErr(c.client, "v fuori da (0, 1]");
        if (!check_target(c.q, cal, err, sizeof err)) return sendErr(c.client, err);
        pl.move(c.q, c.v);
        break;
    case C_STOP:
        if (enabled) pl.stop();
        break;
    case C_ENABLE:
        if (enabled) return;
        if (!known) pl.reset(home), known = true;
        writeServos();
        attachNext = 0;
        tAttach = millis() - ATTACH_STAGGER_MS;  // il primo subito
        enabled = true;
        break;
    case C_RAW: {
        if (!enabled) return sendErr(c.client, "raw solo con enabled");
        if (attachNext < NJ) return sendErr(c.client, "enable in corso");
        if (c.j < 0 || c.j >= NJ || !isfinite(c.v)) return sendErr(c.client, "raw: giunto o us non validi");
        if (pl.moving()) return sendErr(c.client, "raw: braccio in moto");
        // il giunto va dove dice l'impulso: la posa resta coerente, il prossimo move parte da qui senza salti
        float qn = us_to_q(cal[c.j], constrain(c.v, US_MIN, US_MAX));
        float e = (c.j == 1 ? qn : pl.q[1]) - (c.j == 2 ? qn : pl.q[2]);
        if (e < PAR_MIN - 0.001f || e > PAR_MAX + 0.001f) return sendErr(c.client, "raw: fuori vincolo th2-phi");
        pl.q[c.j] = pl.target[c.j] = qn;
        break;
    }
    case C_CAL_GET:
        sendCal(c.client);
        break;
    case C_CAL_SET:
        if (pl.moving()) return sendErr(c.client, "cal_set: braccio in moto");
        if (!check_cal(c.cal, err, sizeof err)) return sendErr(c.client, err);
        // si tiene l'impulso attuale e si rilegge la posa con la nuova taratura: il servo non si muove
        for (int j = 0; j < NJ; j++) pl.q[j] = pl.target[j] = us_to_q(c.cal[j], q_to_us(cal[j], pl.q[j]));
        memcpy(cal, c.cal, sizeof cal);
        sendCal(0);
        break;
    case C_CAL_SAVE:
        prefs.putBytes("cal", cal, sizeof cal);
        break;
    case C_HOME_SET:
        if (pl.moving()) return sendErr(c.client, "home_set: braccio in moto");
        if (!check_target(pl.q, cal, err, sizeof err)) return sendErr(c.client, err);
        memcpy(home, pl.q, sizeof home);
        prefs.putBytes("home", home, sizeof home);
        sendCal(0);
        break;
    }
}

// ---- WebSocket (task AsyncTCP: solo parsing) ----

static void onWs(AsyncWebSocket*, AsyncWebSocketClient* client, AwsEventType type, void* arg, uint8_t* data, size_t len) {
    uint32_t id = client->id();
    if (type == WS_EVT_CONNECT) {
        char s[64];
        snprintf(s, sizeof s, "{\"t\":\"hello\",\"fw\":\"%s\",\"mode\":\"%s\"}", FW_VERSION, netMode);
        client->text(s);
        return;
    }
    if (type != WS_EVT_DATA) return;
    auto* info = (AwsFrameInfo*)arg;
    if (!info->final || info->index || info->len != len || info->opcode != WS_TEXT) return;  // un frame di testo

    JsonDocument doc;
    if (deserializeJson(doc, data, len)) return sendErr(id, "json non valido");
    const char* t = doc["t"] | "";
    if (!strcmp(t, "estop")) {
        estopReq = true;
        return;
    }
    Cmd c = {};
    c.client = id;
    if (!strcmp(t, "move")) {
        c.t = C_MOVE;
        JsonArray q = doc["q"];
        if (q.size() != NJ) return sendErr(id, "move: servono 4 valori in q");
        for (int j = 0; j < NJ; j++) c.q[j] = q[j] | NAN;
        JsonVariant v = doc["v"];
        c.v = v.isNull() ? 0.5f : (v.is<float>() ? v.as<float>() : NAN);  // tipo sbagliato -> rifiutato, non 0.5
    } else if (!strcmp(t, "stop")) c.t = C_STOP;
    else if (!strcmp(t, "enable")) c.t = C_ENABLE;
    else if (!strcmp(t, "raw")) {
        c.t = C_RAW;
        c.j = doc["j"] | -1;
        c.v = doc["us"] | NAN;
    } else if (!strcmp(t, "cal_get")) c.t = C_CAL_GET;
    else if (!strcmp(t, "cal_set")) {
        c.t = C_CAL_SET;
        JsonArray a = doc["cal"];
        if (a.size() != NJ) return sendErr(id, "cal_set: servono 4 giunti");
        for (int j = 0; j < NJ; j++)
            c.cal[j] = {a[j]["ref_us"] | NAN, a[j]["k"] | NAN, a[j]["q_ref"] | NAN, a[j]["min"] | NAN, a[j]["max"] | NAN};
    } else if (!strcmp(t, "cal_save")) c.t = C_CAL_SAVE;
    else if (!strcmp(t, "home_set")) c.t = C_HOME_SET;
    else return sendErr(id, "comando sconosciuto");
    if (xQueueSend(cmdq, &c, 0) != pdTRUE) sendErr(id, "coda comandi piena");
}

// ---- rete ----

static void wifiStart() {
    if (strlen(WIFI_SSID)) {
        WiFi.mode(WIFI_STA);
        WiFi.setHostname(MDNS_NAME);
        WiFi.begin(WIFI_SSID, WIFI_PASS);
        for (uint32_t t0 = millis(); WiFi.status() != WL_CONNECTED && millis() - t0 < STA_TIMEOUT_MS;) delay(100);
        if (WiFi.status() == WL_CONNECTED) {
            netMode = "sta";
            return;
        }
        WiFi.disconnect(true);
    }
    WiFi.mode(WIFI_AP);
    WiFi.softAP(AP_SSID, AP_PASS);  // 192.168.4.1
    netMode = "ap";
}

static String ip() { return strcmp(netMode, "sta") ? WiFi.softAPIP().toString() : WiFi.localIP().toString(); }

void setup() {
    // PWM non agganciato: i pin restano come al boot, bassi grazie ai pull-down da 10k
    Serial.begin(115200);
    for (int j = 0; j < NJ; j++) ledcSetup(j, PWM_HZ, PWM_BITS);

    cal_default(cal);
    memcpy(home, HOME_DEFAULT, sizeof home);
    prefs.begin("braccio");
    Cal saved[NJ];
    char err[80];
    if (prefs.getBytes("cal", saved, sizeof saved) == sizeof saved && check_cal(saved, err, sizeof err))
        memcpy(cal, saved, sizeof cal);
    float h[NJ];
    if (prefs.getBytes("home", h, sizeof h) == sizeof h && check_target(h, cal, err, sizeof err)) memcpy(home, h, sizeof home);
    pl.reset(home);

    cmdq = xQueueCreate(16, sizeof(Cmd));

    wifiStart();
    MDNS.begin(MDNS_NAME);
    MDNS.addService("http", "tcp", 80);
    Serial.printf("BRACCIO %s: %s %s, http://%s.local\n", FW_VERSION, netMode, ip().c_str(), MDNS_NAME);

    if (!LittleFS.begin(false)) Serial.println("LittleFS vuoto o assente: fai uploadfs");
    ws.onEvent(onWs);
    server.addHandler(&ws);
    server.on("/api/info", HTTP_GET, [](AsyncWebServerRequest* req) {
        String s = String("{\"fw\":\"" FW_VERSION "\",\"ip\":\"") + ip() + "\",\"mode\":\"" + netMode + "\"}";
        req->send(200, "application/json", s);
    });
    server.serveStatic("/", LittleFS, "/").setDefaultFile("index.html");  // usa da solo i .gz se presenti
    server.onNotFound([](AsyncWebServerRequest* req) { req->send(404, "text/plain", "404"); });
    server.begin();
}

void loop() {
    static uint32_t tCtl = millis(), tState = millis();
    if (estopReq) {  // i comandi arrivati prima dell'estop non devono essere eseguiti dopo
        estopReq = false;
        xQueueReset(cmdq);
        estop();
    }
    Cmd c;
    while (xQueueReceive(cmdq, &c, 0) == pdTRUE) handle(c);
    attachStep();

    uint32_t now = millis();
    if (now - tCtl >= CTRL_MS) {
        tCtl = now - tCtl > 5 * CTRL_MS ? now : tCtl + CTRL_MS;  // se resta indietro non recupera a raffica
        if (enabled) {
            // watchdog: nessun client connesso durante il moto -> frena e tiene la posizione
            if (!ws.count() && pl.moving() && !pl.stopping) pl.stop();
            pl.step(CTRL_MS / 1000.0f, cal);
            writeServos();
        }
    }
    if (now - tState >= STATE_MS) {
        tState = now;
        if (ws.count()) sendState();
        ws.cleanupClients();
    }
    delay(1);
}

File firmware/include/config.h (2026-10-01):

// Costanti del firmware. Contratto: docs/03-protocollo.md, pin: docs/02-cablaggio.md.
// Se cambiano là (o in cad/params.scad), vanno aggiornate qui.
// Niente Arduino.h: lo includono anche i test nativi.
#pragma once

#define FW_VERSION "0.1.0"

constexpr int NJ = 4;  // 0 base q1, 1 spalla th2, 2 gomito phi, 3 pinza g

// ---- PWM servo (LEDC) ----
constexpr int PIN_SERVO[NJ] = {33, 25, 26, 27};  // adiacenti, non strapping, niente impulsi al boot
constexpr int PWM_HZ = 50;
constexpr int PWM_BITS = 16;  // 20000 us / 65536 = 0.31 us per passo
constexpr float PWM_PERIOD_US = 20000;
constexpr float US_MIN = 500, US_MAX = 2500;  // clamp finale del segnale, sempre

// ---- taratura default (us = ref_us + k * (q - q_ref)) ----
constexpr float CAL_REF_US[NJ] = {1500, 1500, 1500, 1500};
constexpr float CAL_K[NJ] = {11.11f, 11.11f, 11.11f, 19.89f};  // SG90 11.11 us/°; pinza pignone r=16 mm -> 19.89 us/mm
constexpr float CAL_Q_REF[NJ] = {0, 90, 0, 29.5f};
constexpr float Q_MIN[NJ] = {-90, 20, -70, 0};  // ° ° ° mm
constexpr float Q_MAX[NJ] = {90, 160, 70, 59};

// ---- vincolo del parallelogramma: PAR_MIN <= th2 - phi <= PAR_MAX ----
constexpr float PAR_MIN = 35, PAR_MAX = 150;  // 35: sotto, il parallelogramma amplifica la cedevolezza (sim/structural)

constexpr float HOME_DEFAULT[NJ] = {0, 90, 0, 30};

// ---- moto (scalati dal fattore v del comando, tranne la frenata) ----
constexpr float VMAX[NJ] = {90, 90, 90, 60};      // °/s, pinza mm/s
constexpr float AMAX[NJ] = {180, 180, 180, 120};  // °/s², pinza mm/s²

// enable: un servo agganciato ogni ATTACH_STAGGER_MS, non tutti insieme. Un SG90 che salta alla home
// assorbe ~0.7 A per 150-250 ms (costante meccanica ~60 ms col braccio): 4 insieme fanno 2.4-2.7 A di picco
// e portano i servo sotto 4.0 V con cavi USB sottili. Sfalsati: picco ~1.7 A (sim/electrical/out/results.md).
constexpr int ATTACH_STAGGER_MS = 200;

constexpr int CTRL_MS = 20;   // loop di controllo 50 Hz, uno per frame servo
constexpr int STATE_MS = 50;  // broadcast stato 20 Hz

// ---- rete ----
constexpr unsigned STA_TIMEOUT_MS = 10000;
#define AP_SSID "BRACCIO"
#ifndef AP_PASS
#define AP_PASS "braccio-arm"  // default pubblico (repo open source): cambialo in secrets.h
#endif
#define MDNS_NAME "braccio"

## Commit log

2026-09-30 calc: static torque check for sg90 parallel arm
2026-09-30 cad: shared params and pocket helpers
    [params.scad]
2026-09-30 cad: tolerance coupon
    [tolerance_coupon.scad, tolerance_coupon.stl]
2026-09-30 cad: upper arm with lead counterweight tail
    [upper_arm.scad, upper_arm.stl]
2026-09-30 cad: elbow crank with lead block
    [crank.scad, crank.stl]
2026-09-30 cad: turret
    [turret.scad, turret.stl]
2026-09-30 cad: assembly and collision check
    [assembly.scad]
2026-09-30 docs: no-solder wiring, direct gpio
2026-09-30 docs: kinematics, calibration and ws protocol contract
    [params.scad]
2026-09-30 fw: platformio env and no-ota partitions
    [partitions.csv]
2026-09-30 fw: config, pins and default calibration
2026-09-30 fw: wifi sta/ap, ws protocol, ledc servos
2026-09-30 docs: contract update (limits, gripper k, planes)
2026-09-30 web: robot model, fk/ik, limits and part frames
2026-09-30 web: kinematics and motion tests
2026-09-30 web: twin scene, fk/ik panels, waypoints, calibration
2026-09-30 cad: elbow planes, limits, bearing lip and fixed hardware layout
    [params.scad]
2026-09-30 cad: upper arm channel on servo side
    [upper_arm.scad]
2026-09-30 cad: crank with 6-slot lead arc, pairwise hull keeps pin A clear
    [crank.scad]
2026-09-30 cad: turret wider, cable holes inside base opening
    [turret.scad]
2026-09-30 cad: forearm U, leveling link, rods and spacers
    [linkage.scad]
2026-09-30 cad: wrist bracket, rack and pinion gripper, esp32-cam cradle
    [wrist.scad]
2026-09-30 cad: base tray with esp32/breadboard/wago bay and bearing lid
    [base.scad]
2026-09-30 cad: full assembly with hardware, pairwise collision check
    [assembly.scad]
2026-09-30 cad: twin models and export script
    [twin.scad]
2026-09-30 cad: print-ready stls
    [00_tolerance_coupon.stl, 01_base_tray.stl, 02_base_lid.stl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]
2026-09-30 web: real part models and rig from cad
    [base.stl, crank.stl, drive_rod.stl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]
2026-09-30 calc: real masses from stl volumes, design points
2026-09-30 docs: print, hardware and assembly guide
2026-09-30 cad: default horn fit with margin, tolerance notes
    [params.scad]
2026-09-30 cad: lighter base with vents, chamfered lid, front lettering
    [base.scad]
2026-09-30 cad: turret floor lightening windows
    [turret.scad]
2026-09-30 cad: regenerate stls
    [00_tolerance_coupon.stl, 01_base_tray.stl, 02_base_lid.stl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]
2026-09-30 web: parallax branding, regenerated models
    [base.stl, crank.stl, forearm.stl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]
2026-09-30 docs: coupon optional, filament and color notes
2026-10-01 cad: fix stale L3/tcp_dz in params
    [params.scad]
2026-10-01 cad: side-entry cable slots, bundle anchor, raised esp32 cradle, cable paths
    [assembly.scad, base.scad, cables.scad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]
2026-10-01 cad: regenerate stls and twin models
    [00_tolerance_coupon.stl, 01_base_tray.stl, 02_base_lid.stl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]
2026-10-01 docs: esp32 mounting and cable routing with lengths
2026-10-01 fw: staggered servo attach on enable (200 ms) to cut inrush
2026-10-01 docs: wiring updated from electrical sim (short cable, 2200uF, estop, grip)
2026-10-01 sim: mujoco dynamics with real firmware planner, servo/friction/backlash model
    [current_profiles.csv]
2026-10-01 cad: 4-slot arm tail, collision grid script with sag pose and negative control
    [upper_arm.scad]
2026-10-01 calc: leveled gripper loads elbow at L2, 2+4 lead split
2026-10-01 docs: 50 g with camera, lead split, nut preload test
2026-10-01 web: robust cal validation, no proto copy, envelope cap, gizmo yaw jump guard
2026-10-01 fw: calibration limits cannot exceed mechanical range (+test)
2026-10-01 sim: structural, pin, gear, snap, creep and monte carlo tolerance analysis
    [run_all.py]
2026-10-01 cad: jaw dovetail neck (was detached), bracket nut pitch 7.5, thicker fingers
    [wrist.scad]
2026-10-01 cad: servo/horn fit margins, taller gussets, wider ribbed arm, e>=35, screw notes
    [assembly.scad, base.scad, crank.scad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]
2026-10-01 sim: structural reads arm/gussets from cad; tests and dynamics on the 35 deg edge
    [current_profiles.csv]
2026-10-01 docs: threadlock, grease, constraint 35
2026-10-01 docs: steel bolt for elbow pin
2026-10-01 cad: ribs end at x=45 so the folded forearm clears them
    [00_tolerance_coupon.stl, 01_base_tray.stl, 02_base_lid.stl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]
